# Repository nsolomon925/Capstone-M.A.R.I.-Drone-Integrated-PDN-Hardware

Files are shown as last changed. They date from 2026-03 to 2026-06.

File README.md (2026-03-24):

# M.A.R.I. Drone: Integrated Power Distribution Network (PDN)

## Project Overview
This repository documents the design, simulation, and physical implementation of a high-performance Power Distribution Network (PDN) for the M.A.R.I. Quadcopter. As the **Power Systems Lead**, I engineered a triple-domain power architecture capable of supporting high-current flight demands while maintaining clean, isolated voltage rails for sensitive avionics and sensors.

## Key Technical Specifications
* **Dual Battery Support:** Validated for both **3S (12.6V)** and **4S (16.8V)** LiPo configurations.
* **Peak Current Capacity:** Engineered to handle **71.6A peak** during maximum ascent maneuvers.
* **Triple-Domain Architecture:** * **16.8V High-Power Bus:** Direct battery rail for the 40A ESCs and motors.
    * **5V Logic Rail:** Driven by the **AP63300** Buck regulator for the MCU and LoRa modules.
    * **3.3V Analog Rail:** Dual **TLV75533** LDOs providing isolated power for the IMU and Barometer.
* **Flight Endurance:** Optimized for a **9.4-minute** hover time.
* **Safety Systems:** Integrated hardware-level voltage divider for a **1.4V** battery monitoring threshold.

## Repository Structure
The project is organized into a professional engineering hierarchy for technical validation and production:

### 📁 `/analysis`
Contains all theoretical and simulated validation for the power system.
* **`/mathcad`**: Static power integrity and thermal loading worksheets.
* **`/spice`**: LTspice transient and noise analysis for 12.6V and 16.8V domains.
* **`/power_budget`**: System loading models and endurance calculations.

### 📁 `/design`
Includes the physical and logical implementation of the hardware.
* **`/hardware`**: Hierarchical schematics, PCB layout captures, and 3D renders.
* **`Block Diagram.pdf`**: High-level system architecture and signal flow.

### 📁 `/budget`
Focuses on the production and component selection.
* **`Bill of Materials.xlsx`**: Full parts list with 35V+ rated components for 4S compatibility.

### 📁 `/reports`
Executive summaries and performance verification.
* **`Final_Design_Review.pdf`**: Comprehensive system overview.
* **`Project_Report.pdf`**: Final flight testing and hardware validation results.

## Engineering Highlights
* **Parasitic Modeling:** Used LTspice to simulate the impact of **12 AWG** wiring and **XT90** connector inductance ($L_w$) on voltage ripple using parametric stepping.
* **EMI Isolation:** Implemented dual LDOs to decouple high-frequency switching noise from sensitive flight sensors.
* **Robustness:** All power components are rated for **25V-35V** to ensure safety during the high-voltage swings of a 4S battery.

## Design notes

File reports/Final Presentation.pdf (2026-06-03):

# MARI Drone

Team:
Seth Iris Canonigo
Connor Prior
Christopher Ruiz-Guerra
Nahom Solomon

## Modular Aerial Real-Time Instrument (M.A.R.I)

### Flying Quadcopter Drone

Features:

- User control with Radio Controller
- Self-Stabilization
- Altitude-lock
- Modular - easily able to add additional features

## Quadcopter Drone Flight

- We use 4 motors/propellers to control the drone
- Forward/back/left/right movement is achieved by tilting the drone using unequal levels of thrust in each motor
- Propellers must move in opposite directions so the drone doesn’t spin in the same direction as the propellers
- Control Equations:

Motor(Front Left) = throttle - roll - pitch + yaw

Motor(Front Right) = throttle + roll - pitch - yaw

Motor(Rear Right) = | throttle + roll + pitch + yaw
Motor(Rear Left) = | throttle - roll + pitch - yaw
- Values for throttle, roll, pitch, and yaw will be controlled by user

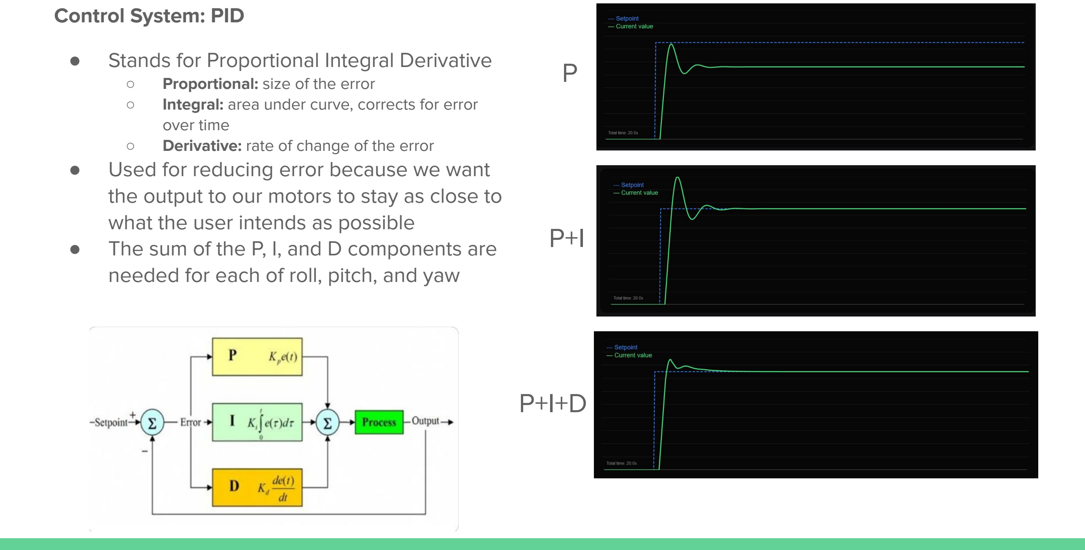
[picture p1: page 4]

Control System: PID

- Stands for Proportional Integral Derivative
- Proportional: size of the error
- Integral: area under curve, corrects for error over time
- Derivative: rate of change of the error
- Used for reducing error because we want the output to our motors to stay as close to what the user intends as possible
- The sum of the P, I, and D components are needed for each of roll, pitch, and yaw

P

P+I

P+I+D

## Block Diagram

## Power

Key Priorities:

- Stable operation across battery voltage drop
- Noise mitigation and safe filtering
- Battery health monitoring safety

## Power Overview

Power Architecture:

- High Current Path: Battery -> ESCs (up to 104 A / 16.8V and 110.4 A / 12.6 V)
- Low Current Path: Battery -> Buck Converter -> LDOs
- Separate regulated rails for MCU, RF Receiver, Sensors, LORA
- Integrated ADC-based battery monitoring circuit for live voltage tracking
Major Loads:
- ESCs: 104 A Peak / 16.8 V (26 amps per ESC) or 110.4 A Peak / 12.6 V (27.5 amps per ESC)
- 5 V Rail: ~0.84 A (RF Receiver + LDO input)
- 3.3 V Rail A: ~0.203 A (IMU, Lora)
- 3.3 V Rail B: ~0.409 A (MCU, Barometer, Oscillator)

## Battery: Gens Ace 3SP1 LiPo

- 11.1 V nominal, 12.6 V max
- 5300 mAh, 60C discharge
- 318 A max continuous output capability
- Easily supports drone peak ~110 A flight load

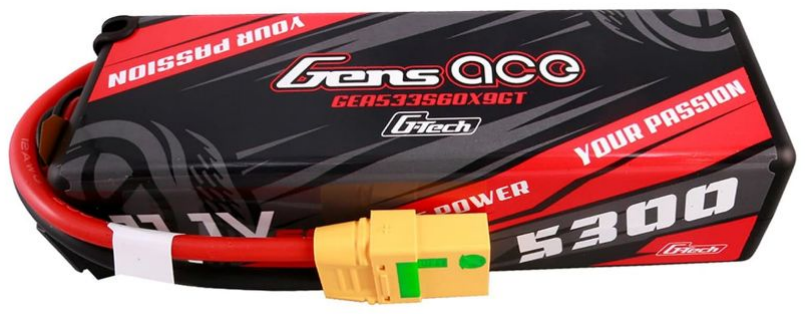
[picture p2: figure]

- XT90s main connector; supports high current draw
- Powers entire system
- Battery stress < 33% of rating
- Expected Flight Time (413g / 0.911 lbs):
- Hover: 3.846 - 4.613 min
- Ascend: 2.88 - 3.455 min

## 5 V Buck Converter - AP63300WU-7 (Diodes Inc.)

- 3A synchronous buck regulator
- Converts 16.8 V (max battery) ---> 5 V regulated
- High efficiency (~90%) to reduce heat and extend flight time
- Powers RF receiver and supplies input to two separate 3.3 V LDO rails
- LC output filter + bulk capacitance to minimize ripple from ESC switching

## 3.3 V LDO Regulator: TLV75533PDYDR (Texas Instruments)

- Low noise, precision LDO rated for 500 mA
max
- Regulates 5 V → 3.3 V for MCU & sensors
- LDO A supports ~204 mA combined load (IMU, LORA)
- LDO B supports ~409 mA combined load (MCU, Barometer, Oscillator)
- Provides clean supply ideal for sensitive components

## Schematic: Power

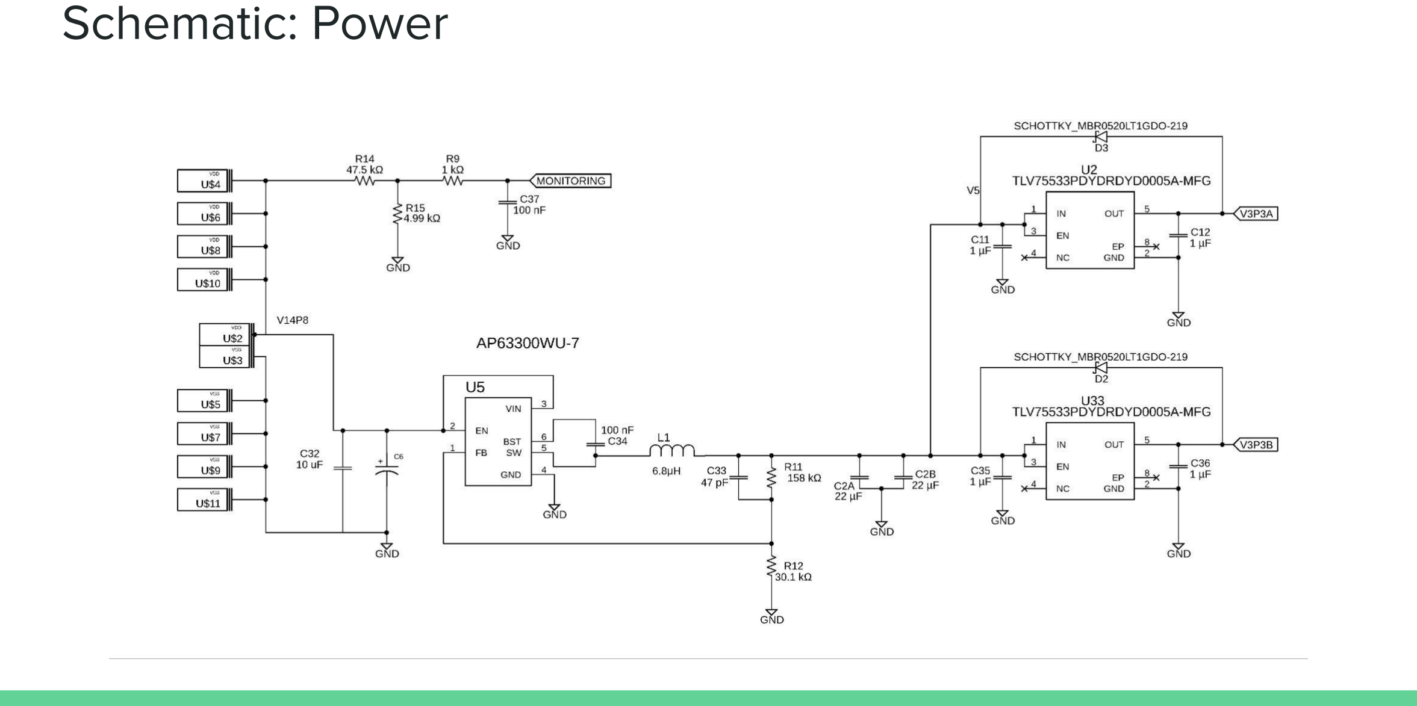
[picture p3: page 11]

## Schematic / LT Spice (12.6 V / 16.8 V)

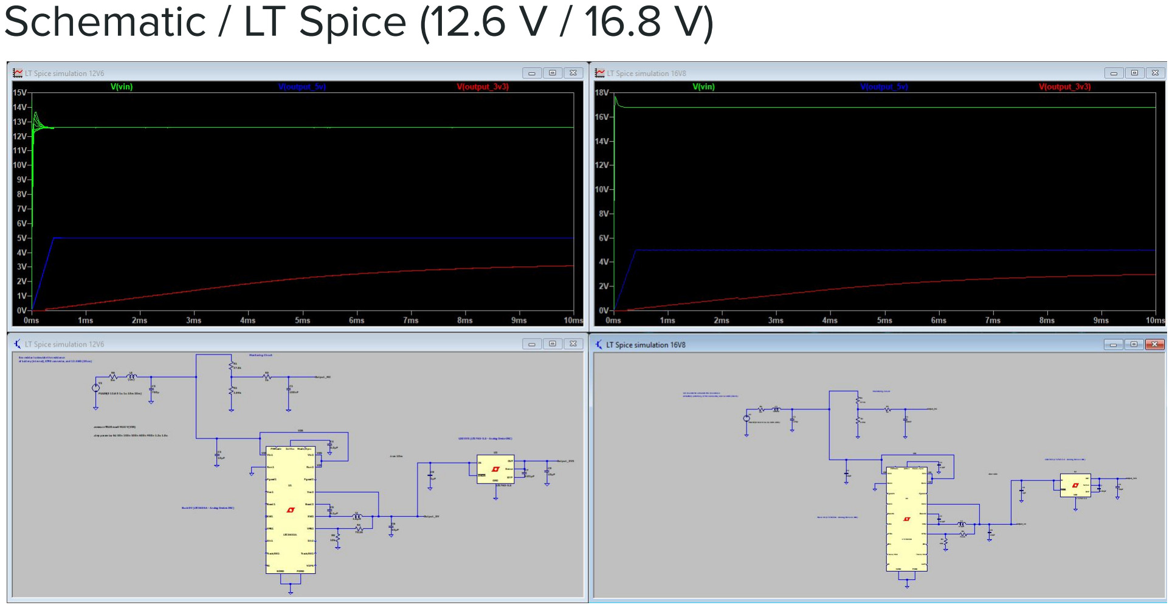
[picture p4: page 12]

## PCB Layout: Power

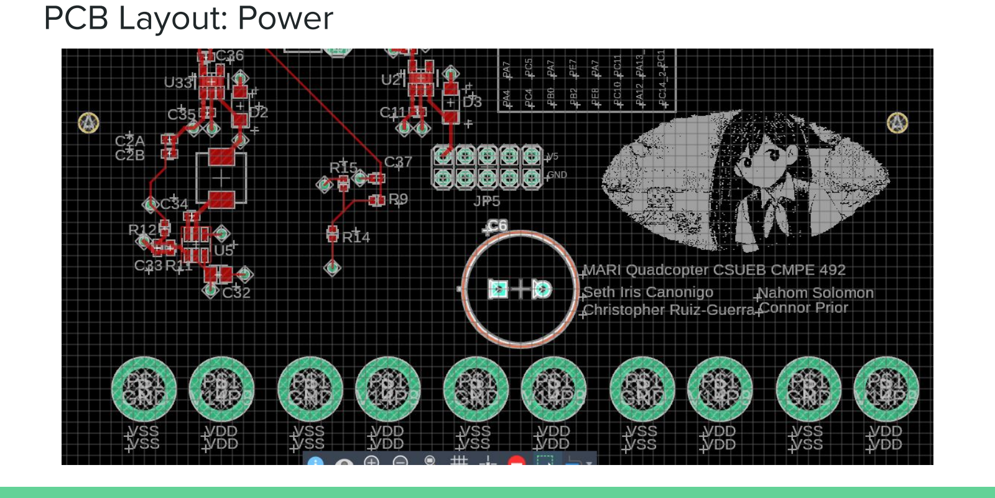
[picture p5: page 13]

## PCB Layout: Power

## Radio Controller / Receiver

Purpose

- Controller: Allows user to control the drone using control sticks.

Communicates with Radio Receiver in Express Long Range System

(ELRS) protocol

- Receiver: Allows the use of 6 PWM Channels, Requiring only 4 Channels

to control Pitch, Yaw, Roll and Throttle

Output

- Controller ⇒ Receiver ⇒ MCU⇒ ESC⇒ Motor
- PWM signals are taken as input for our MCU to calculate balanced PWM outputs to our ESC

## Electronic Speed Controller(ESCs) : RCElectricParts 30A

- Main Purpose: Control rotational speed of motors
- Utilizes PWM signals to vary power from battery towards

motors through MOSFET switching

## Motors: Emax ECO II Series 2807 3-6S 1300KV

- Purpose: Spins propellers to generate
thrust per motor
- Expected weight 5lbs
- Each motor must produce 567 Grams of thrust
- Allows maneuverability via flight equations

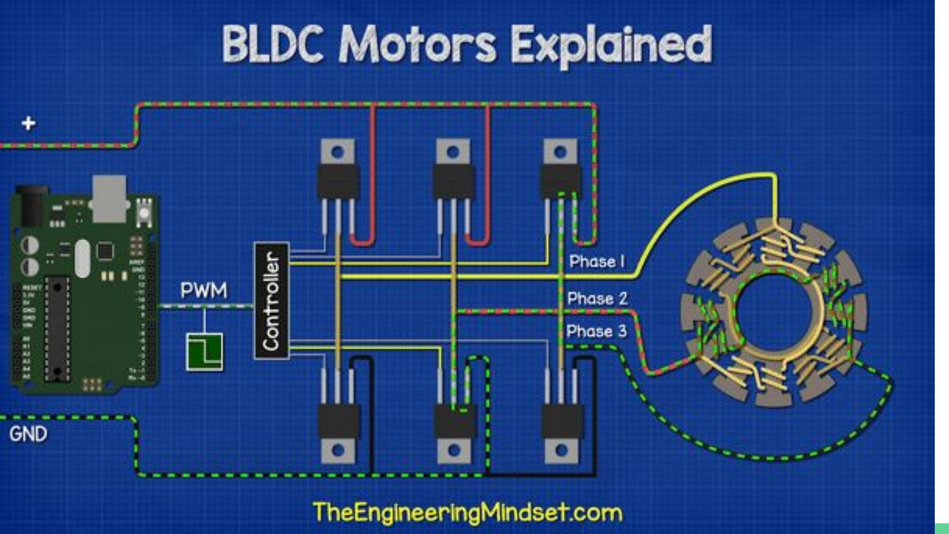
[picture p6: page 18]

## IMU (Inertial Measurement Unit): BNO085

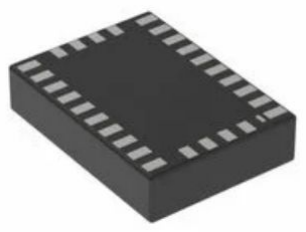
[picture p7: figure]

- Main Purpose: Stabilizing the Drone
- Detects the orientation and
speed/acceleration of the drone
- Main Components:
- Gyroscope - measures angular velocity
- Accelerometer - measures linear acceleration
- Magnetometer - measures direction of magnetic field
- Fusion mode allows the BNO085 to:
- Calculate Euler Angles (Roll, Pitch, Yaw)
- Minimize error using multiple sensors
- Sends data to the microcontroller through I2C protocol

## Schematic: BNO085

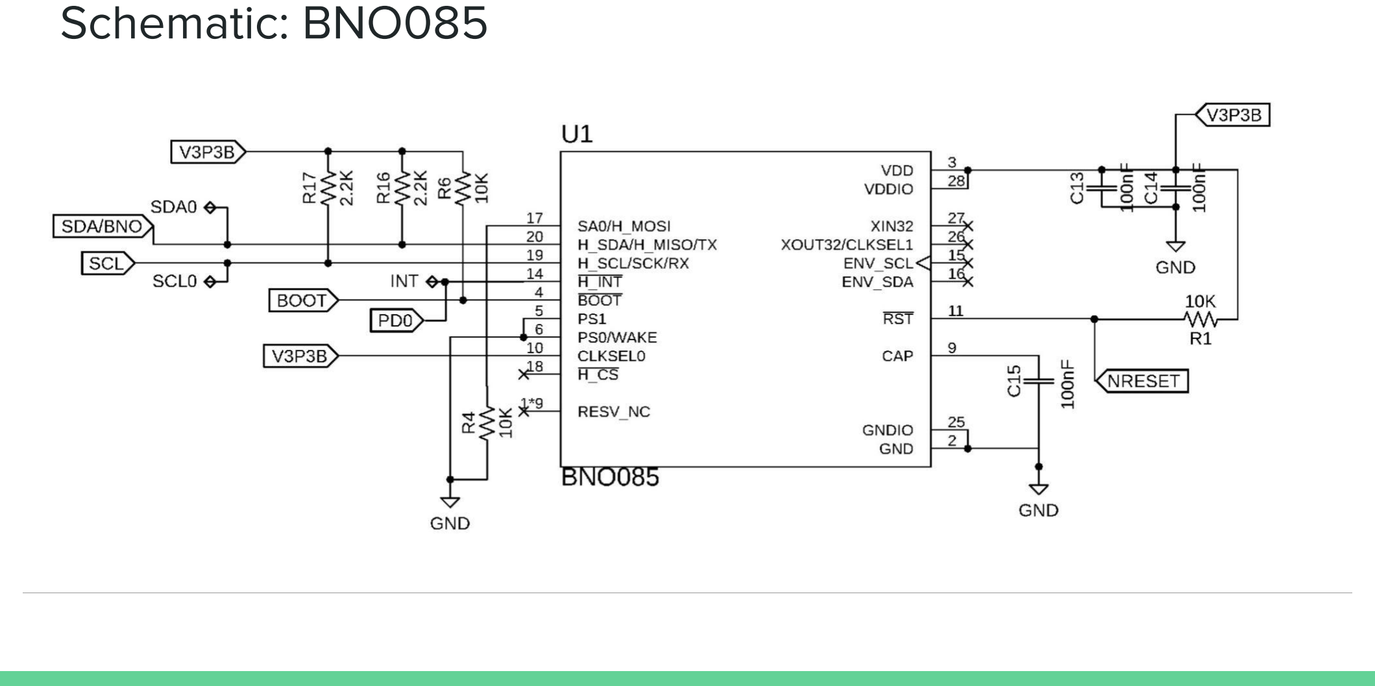
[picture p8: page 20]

## PCB Layout: BNO085

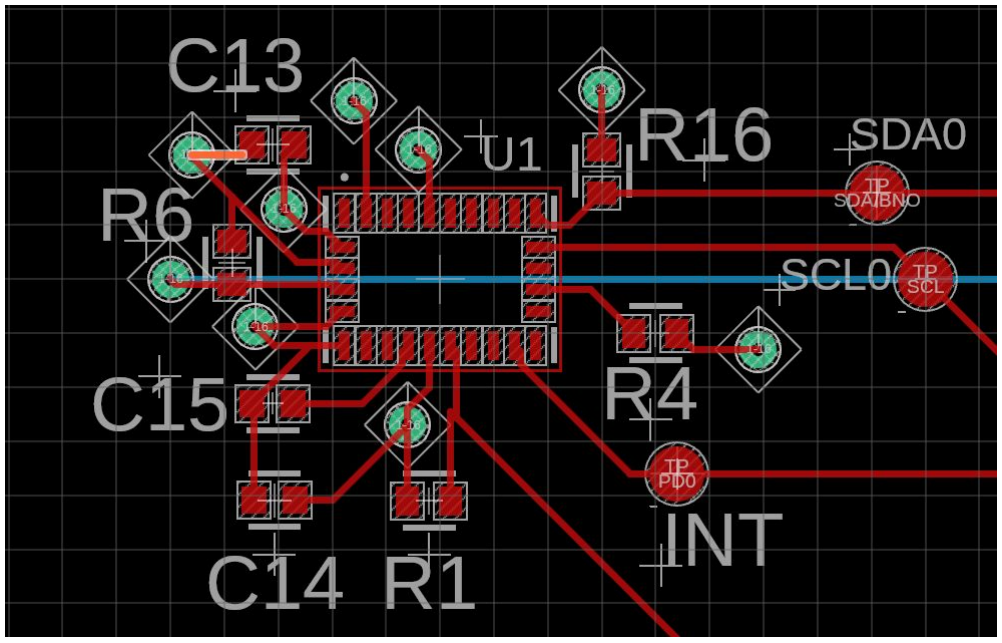
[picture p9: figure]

## Barometer: BMP581

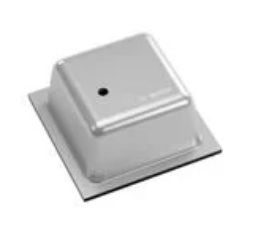
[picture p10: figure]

- Main purpose: measuring the altitude of the drone.
- Sends data to microcontroller through I2C.
- Data will be used to limit the height the drone will be able to fly at.

## Schematic: BMP581

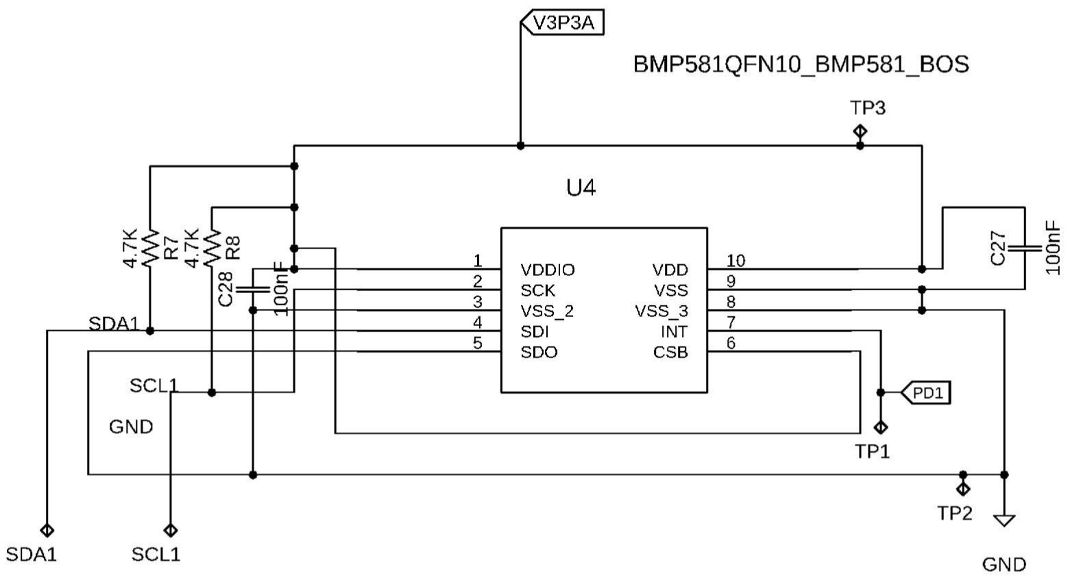
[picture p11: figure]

## PCB Layout: BMP581

## Microcontroller STM32F756VGT6

- MCU is the brain of MARI.
- Takes in input signals, runs all calculations, and outputs the PWM signals for the ESCs.
- Runs at 216 MHz with external crystal
- 100 total pins

Voltage warning light (1 in signal)

Barometer I2C (3 in signals)

IMU I2C (3 in signals)

16 MHz Oscillator (1 in signal)

RF PWM (4 in signals)

ESC PWM (4 out signals)

13 input pins

5 out pins LoRa UART RX

LoRa UART TX

## Schematic: Microcontroller 1

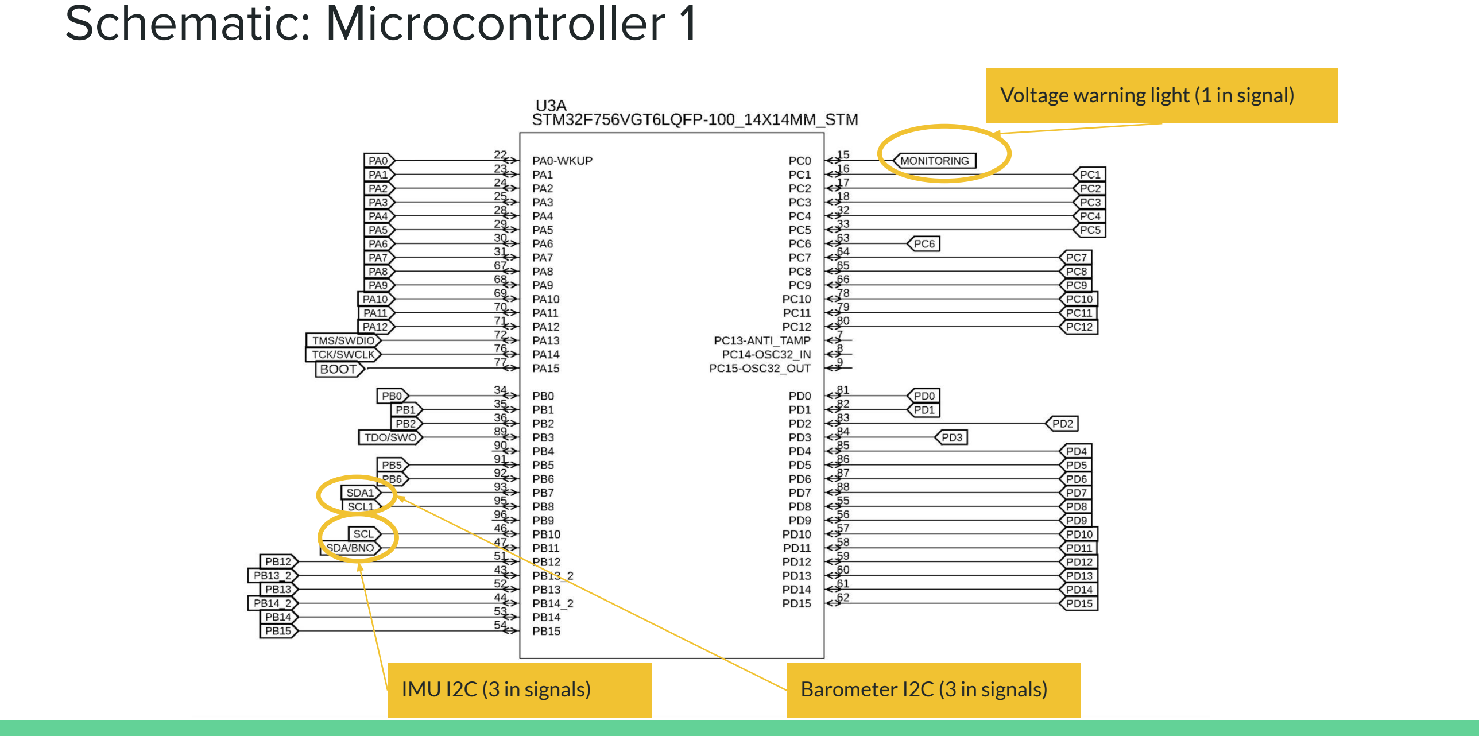
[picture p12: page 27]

Voltage warning light (1 in signal)

IMU I2C (3 in signals) | Barometer I2C (3 in signals)

RF PWM (4 in signals)
ESC PWM (4 out signals)

## Schematic: Microcontroller 2

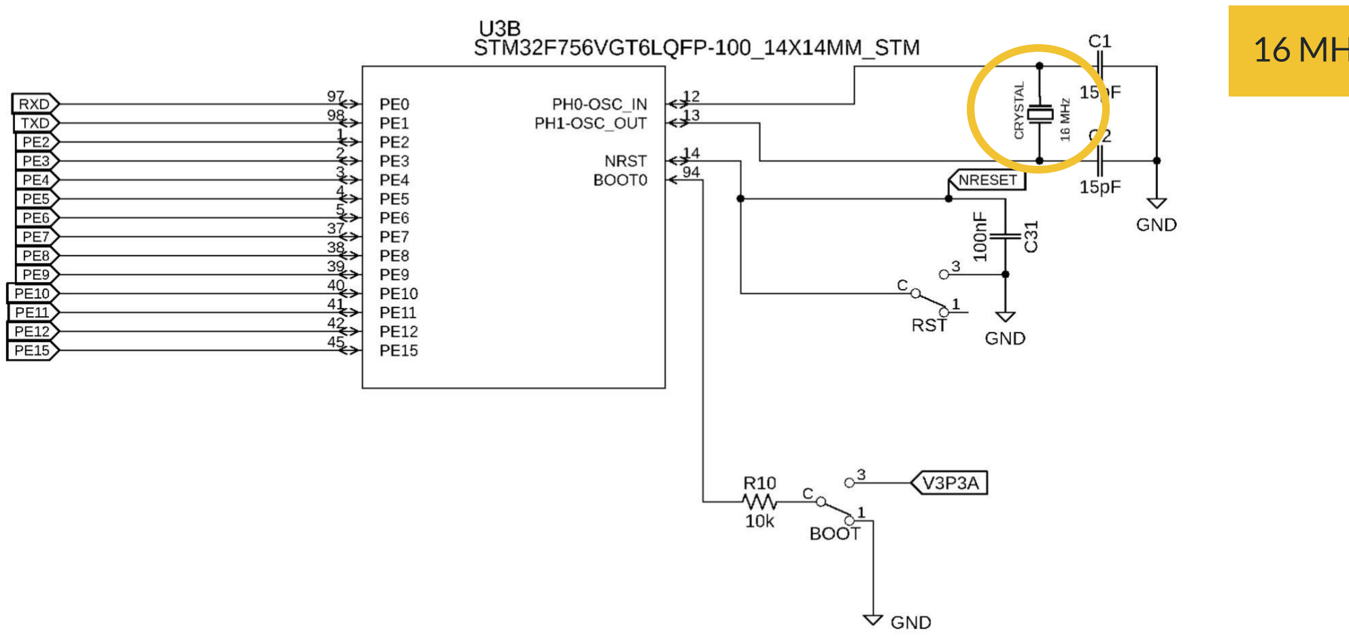
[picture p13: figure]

16 MHz Oscillator (1 in signal)

## Schematic: Microcontroller 3

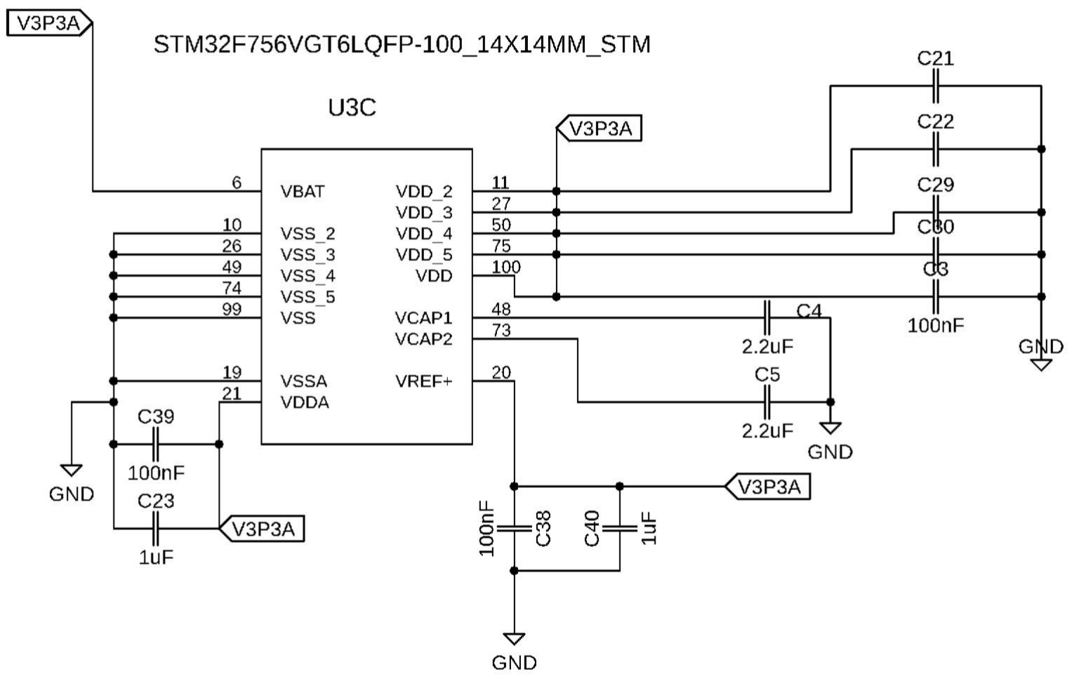
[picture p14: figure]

## PCB Layout: Microcontroller

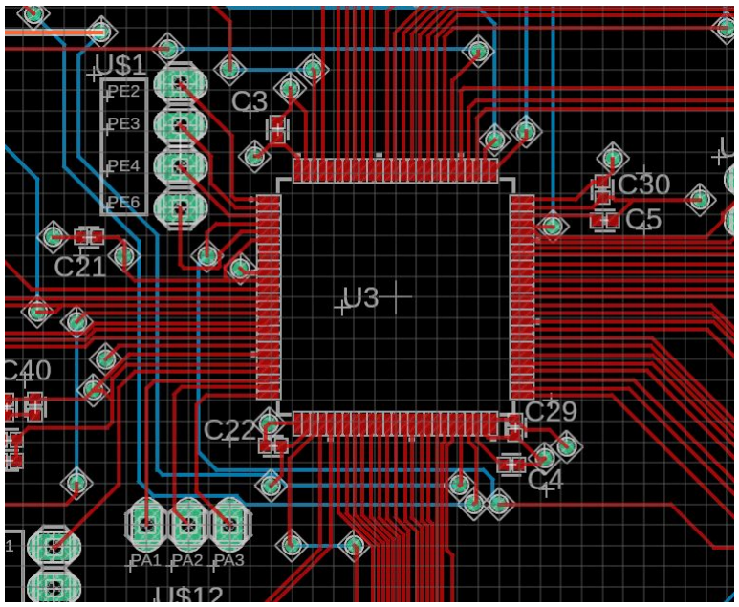
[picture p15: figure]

## Long Range (LoRa) Telemetry: REYAX RYLR998

RYLR998 module is a UART-controlled
LoRa transceiver.

It is low power (56.6 mA) and cheap

Can send data with AT+SEND=...

Can receive data with +RCV=...

Depending on configuration, it can go over a kilometer in distance with limited data rates.

## Hassles of LoRa

- Data rate is abysmal for real-time telemetry
- Only 240 Bytes per payload
- Default Throughput: 190 Bytes/s
- Default Latency 190.7 ms

If I send a packet per second, there will be data loss.

Obviously this is not including RX.

Meaning we had to be picky about what we send from the drone to the receiver

## SWD (Serial Wire Debug) via ST-Link (SWJ)

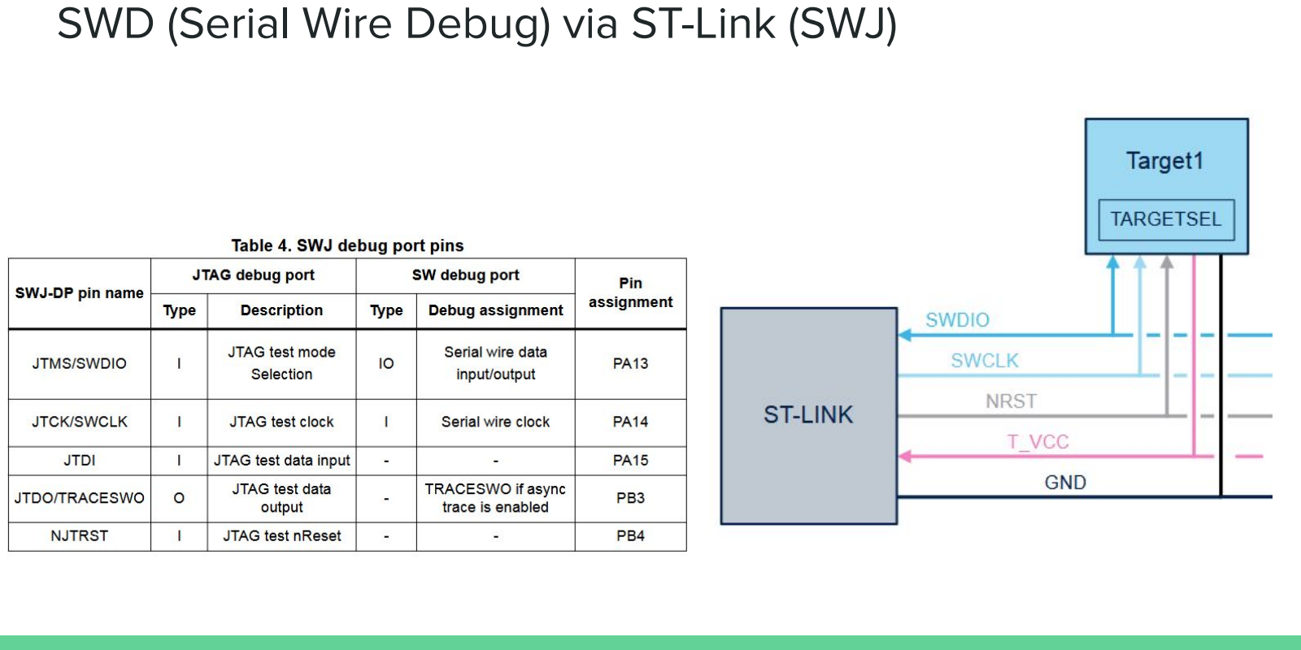
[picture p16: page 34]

## Schematic and PCB Layout: Serial Wire Debug Programming Pins

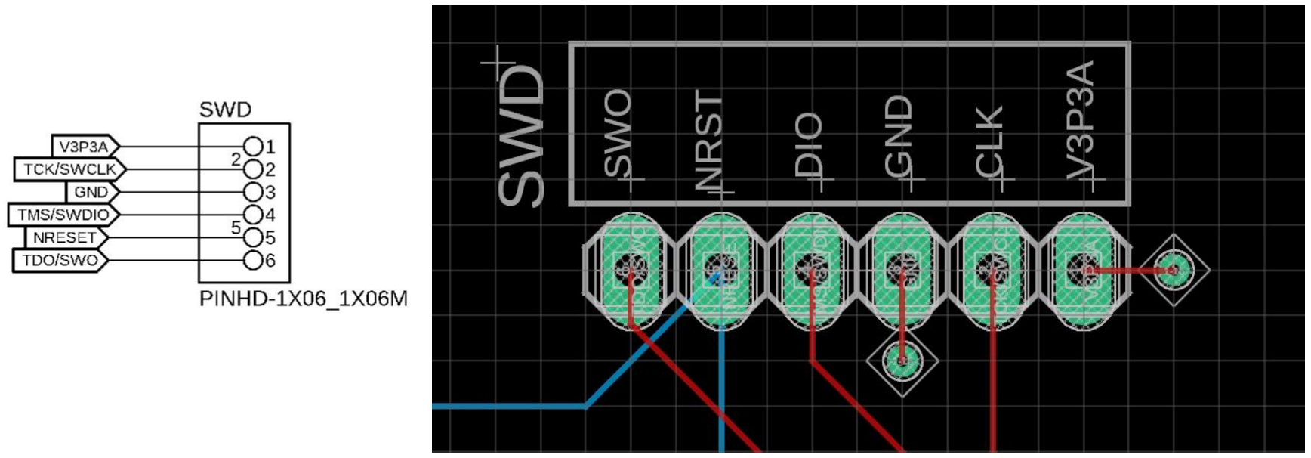
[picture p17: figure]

## Extra Pins

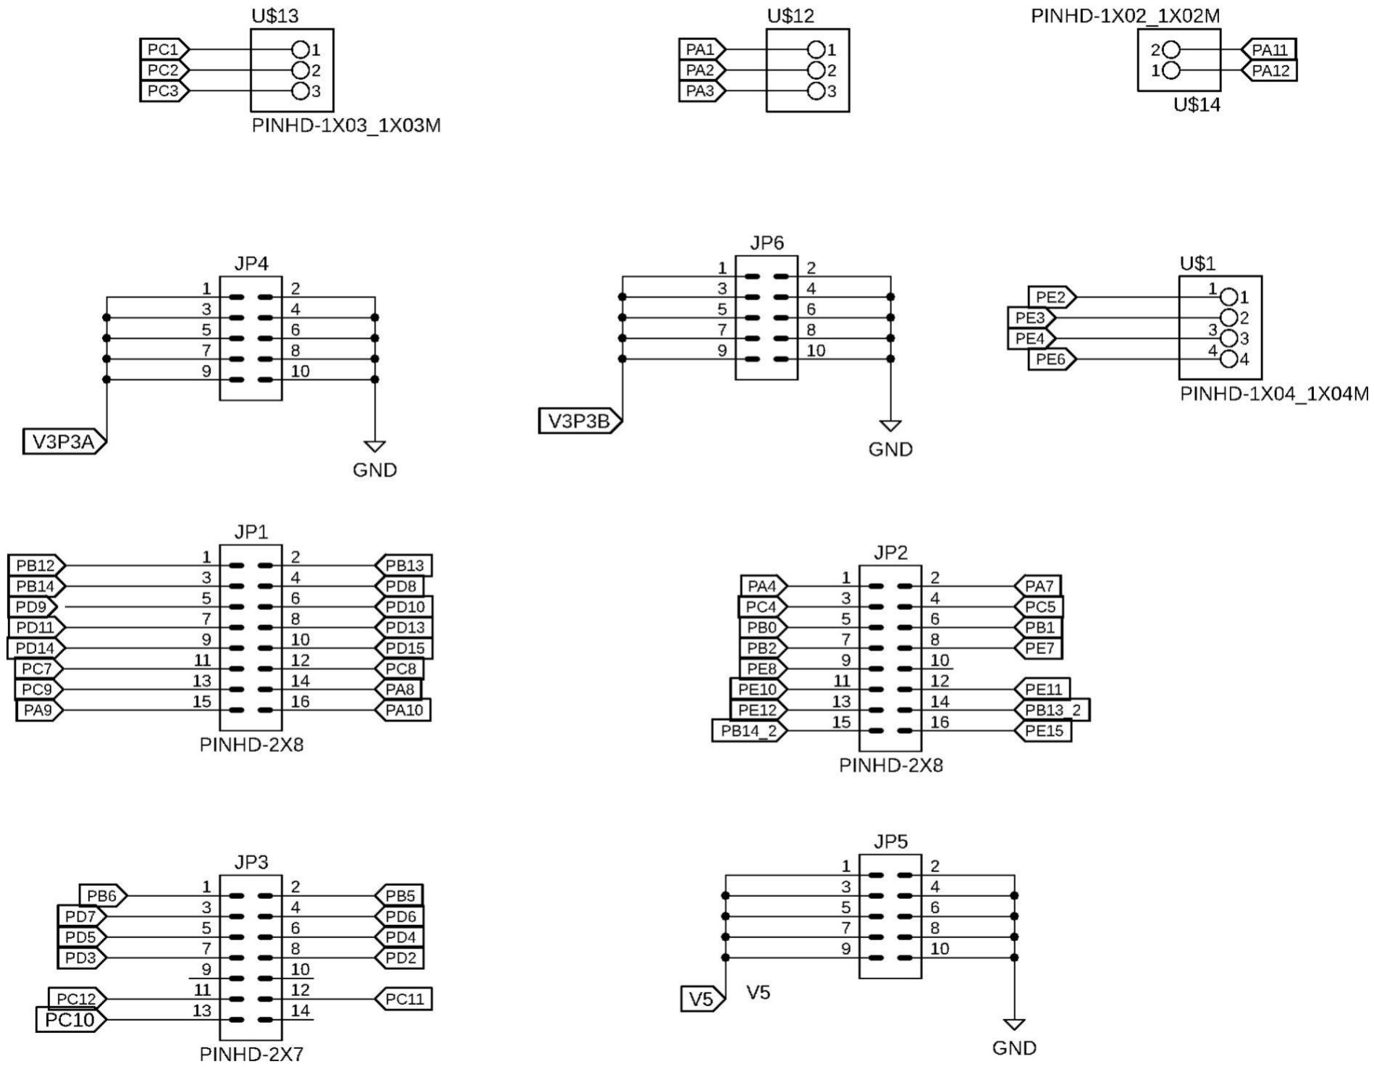
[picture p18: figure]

## Overall Schematic

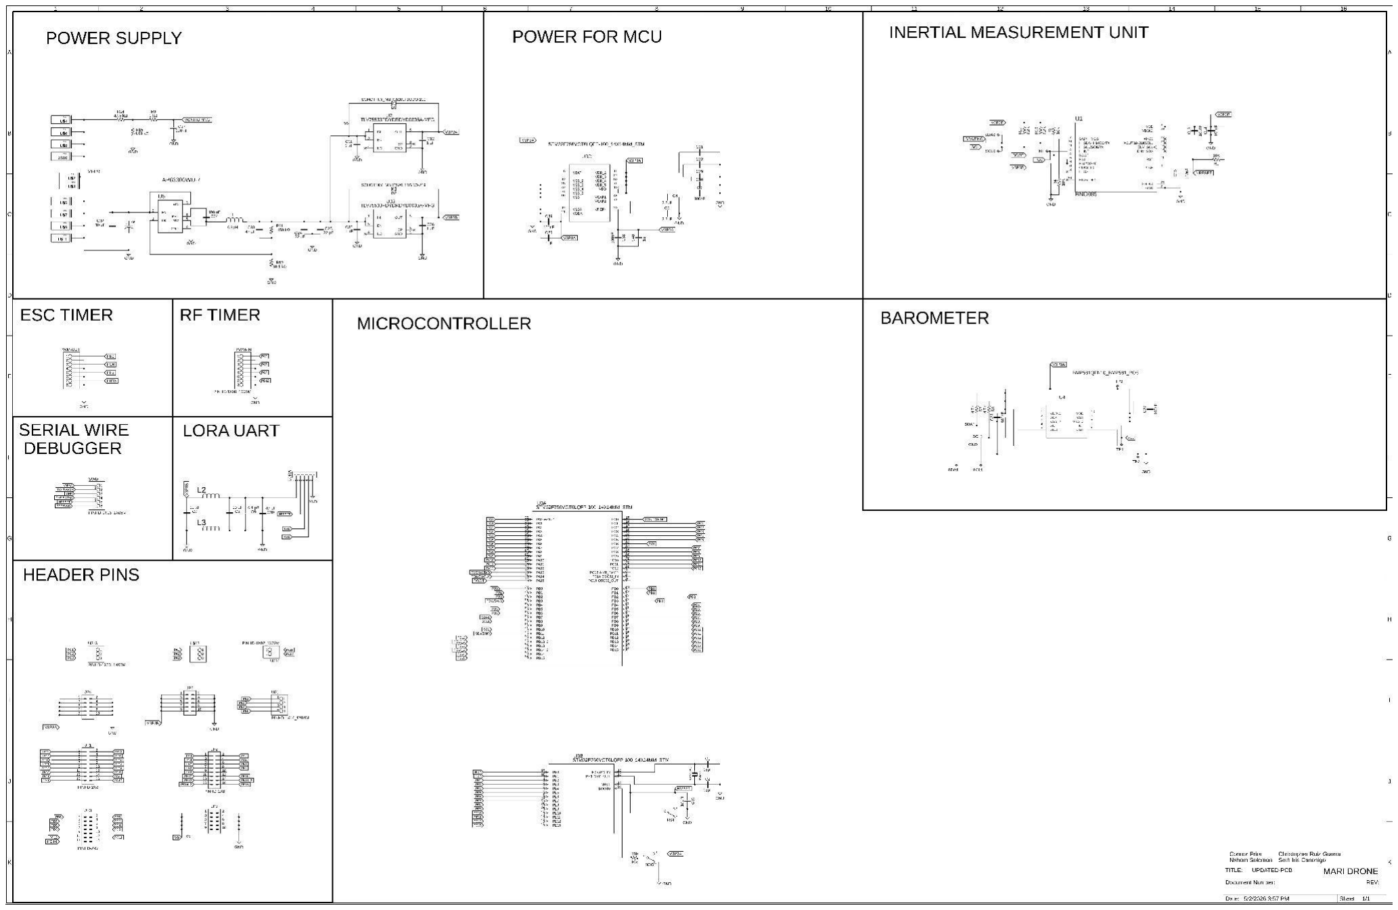
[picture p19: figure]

## Software STM32CubeIDE

- It is the development IDE tool we are using for
programming the
STM32F7.
- It does the entire bootup sequence for us and also
generates initialization
code for all of the
peripherals
- All of this is loaded into the STM’s flash memory

## Official API and drivers

## DMA and NVIC (and EXTI)

Because UART is very slow (blocking), it essentially slows down our flight loop, even if the CPU is running at 216 MHz.

That’s why we used Direct Memory Access (DMA) to combat that.

It moves UART8 TX data from Memory to Peripheral and RX data from Peripheral to Memory without slowing down the flight.

The Nested Vectored Interrupt Controller (NVIC) basically handles all our interrupts even the external ones (EXTI)

## Real-time Operating System (FreeRTOS)

Instead of one giant loop, we used a
Real-Time Operating System (RTOS) to
help manage the various tasks.

FreeRTOS is a popular RTOS and is actually Middleware in CubeIDE using the “wrapper" called CMSIS-RTOS2 to link with the FreeRTOS kernel.

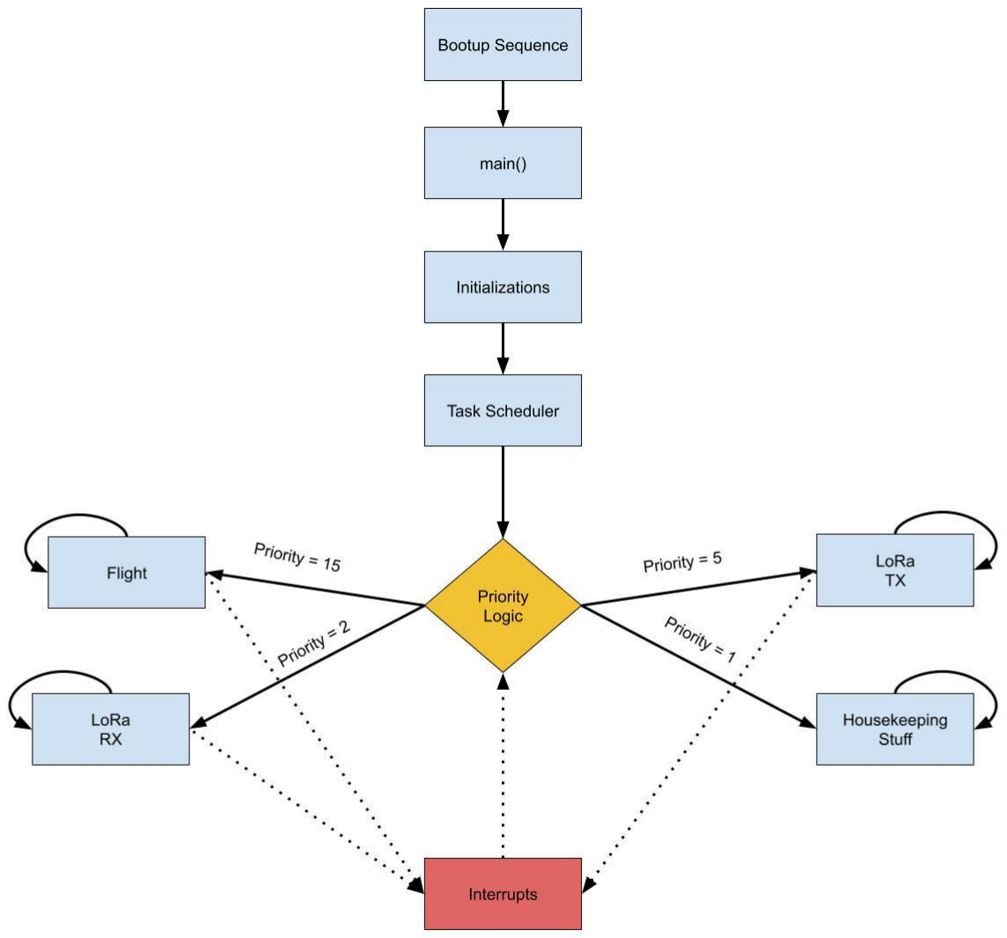
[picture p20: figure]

There are four tasks (FlightTask, TelemTx, TelemRx, and Housekeeping) for the RTOS and three interrupt conditions.

Realistically, running four at the same time with a single core is impossible.

BUT… we can give the illusion that it can by switching between tasks really fast and efficiently via a task scheduler.

## Tasks

## FlightTask (800 Hz - Interrupt-driven)

Purpose: Handles the core flight control
loop, including reading IMU data,does
PI, and updating motor PWMs.

## TelemRx (Interrupt-driven)

Purpose: Processes RX UART data from the LoRa, including handling "Sunny" pings, "Mari" commands.

Purpose: Manages the scheduled transmission of telemetry data (IMU, motor states, battery, and PID values) back to the ground station.

## TelemTx (100 Hz)

## Housekeeping (10 Hz)

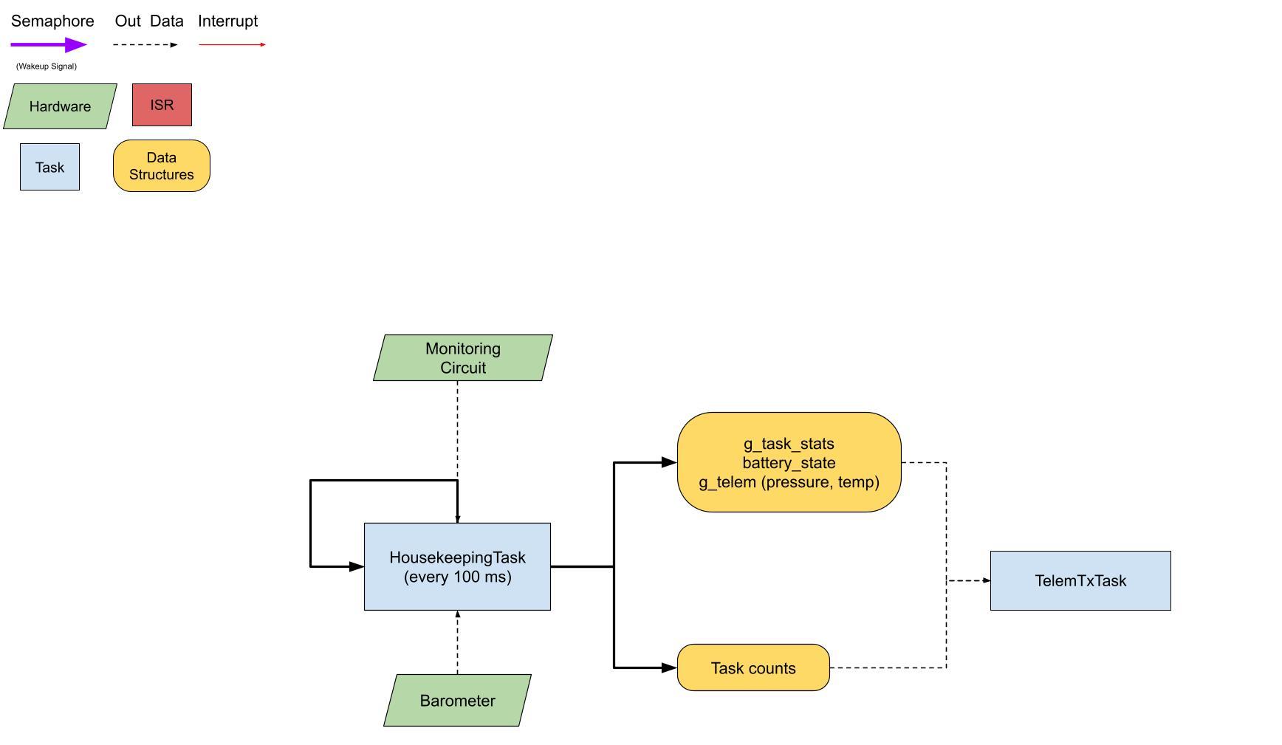
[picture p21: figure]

Purpose: It calculates how loops per second each task does (Hz), updates CPU usage statistics, reading battery voltage, and updating the barometer data.

## Task Priority

To achieve this, task execution is based on priority and must also ensure that resources are allocated properly.

It uses a combination of polling and interrupts to achieve our results
TelemRxTask

FlightTask

HousekeepingTask

High

Medium

Low

TelemTxTask

## Tasks for the MARI

## Task Scheduler

RTOS; LOW; MEDIUM; HIGH; ISR; tick; Housekeeping; Flight; Sensor; PID

## MARI LoRa Monitor

To keep track of the data and parse the data we get from the LoRa telemetry.

It functions as serial monitor, graphing tool,

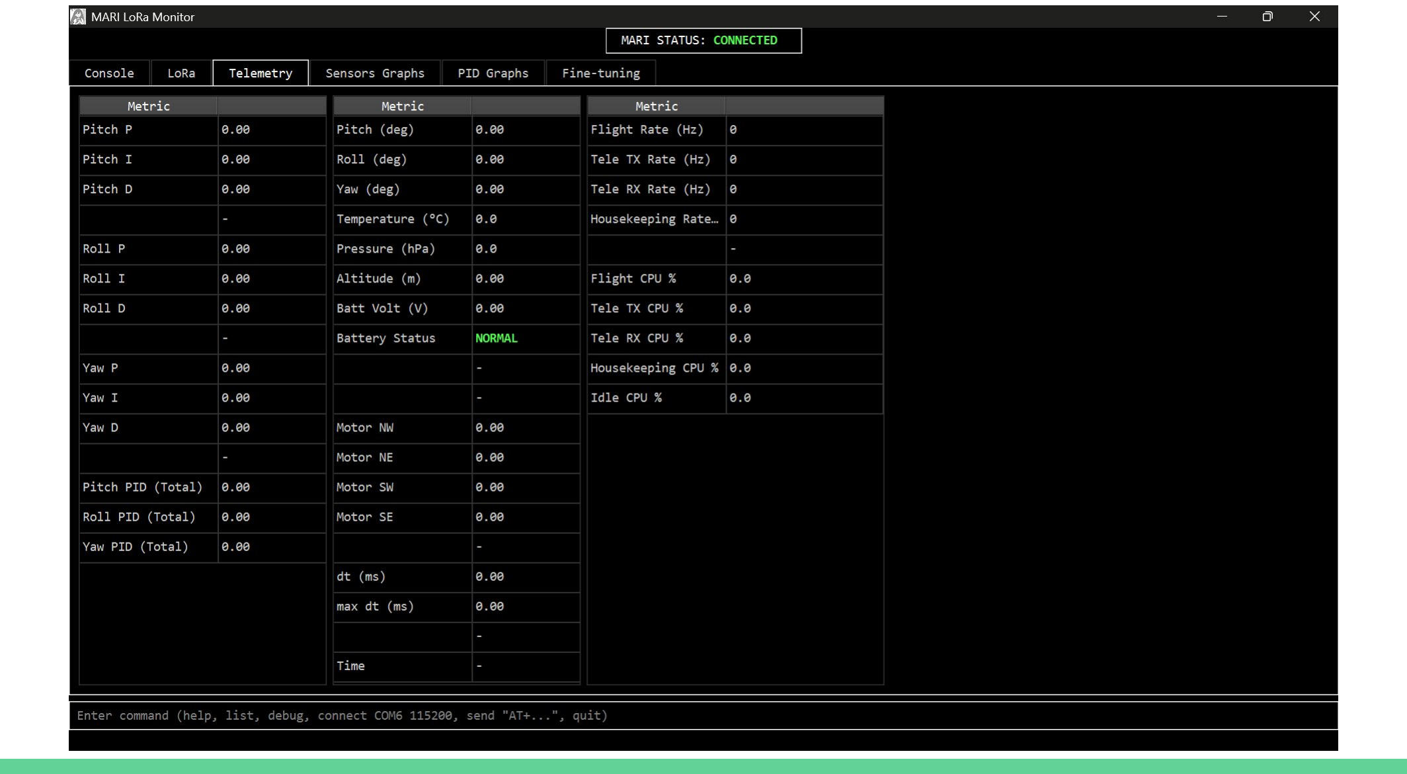
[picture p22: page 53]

## Version 1 and 2 (Plain terminal)

## Version 3 (switched to Textual)

## Version 4 (Remote Monitor)

## Version 5 (switched to GUI, specifically PyQT6)

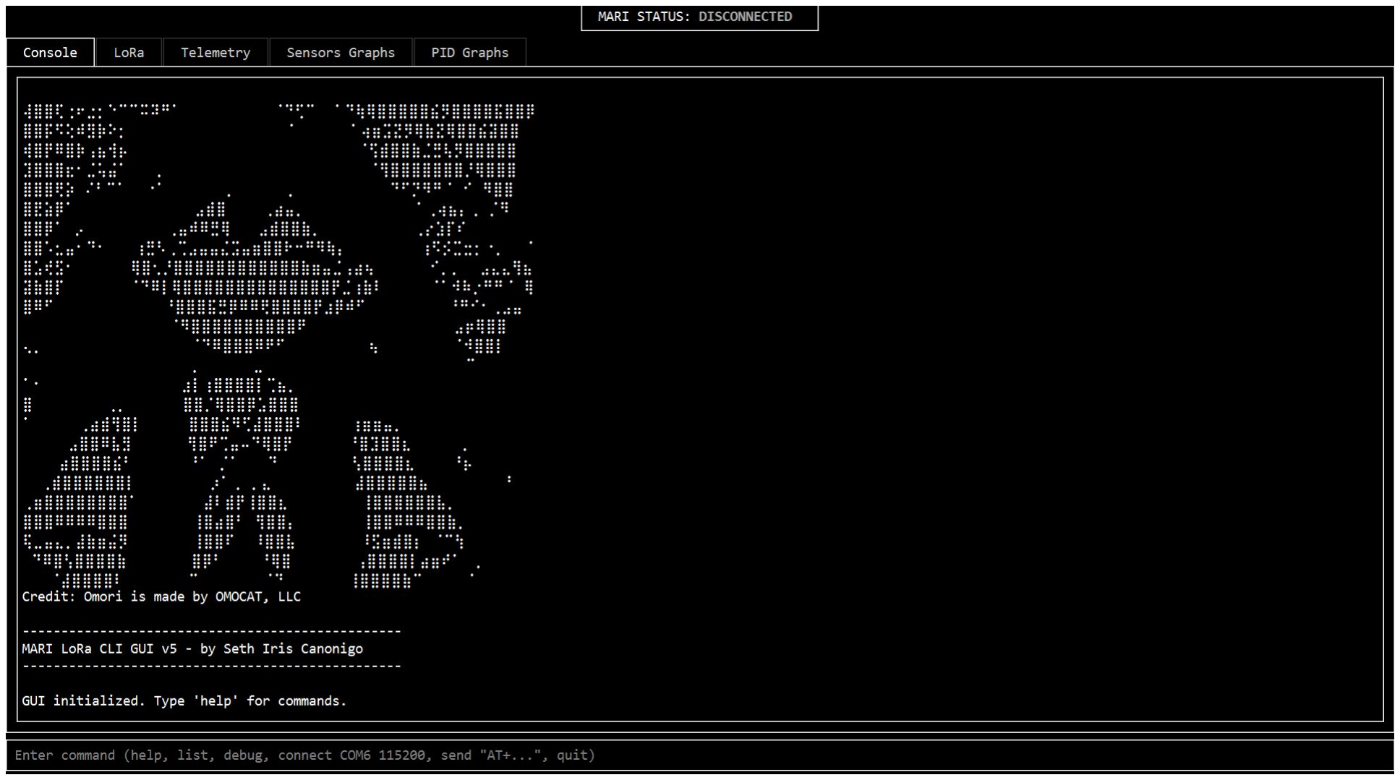
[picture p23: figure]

## Graphs

## Difficulties: Needed to respin PCB

The first iteration of our PCB design was riddled with flaws:

- Zener diode was backwards
- Ultra-short burst, high-current draw causing a voltage spike
- The IMU was stuck in HID outputs
- LoRa was drawing too much current for the LDO
- LoRa had a lot of noise due to incorrect application configuration
- Missing VDD and VSS labels

## PCB Failure Analysis: Fried BUCK & IMU

## Causes: Transient Voltages

## New PCB

Changes

- Faster IMU (400 Hz vs 100 Hz)
- More power for LoRa (22 dBm vs 1 dBm)
- We have two LDOs for two separate 3.3 V planes
- New buck converter with inductor
- Big 1000 uF cap to dampen the spike
- Labeled everything

## Old PCB

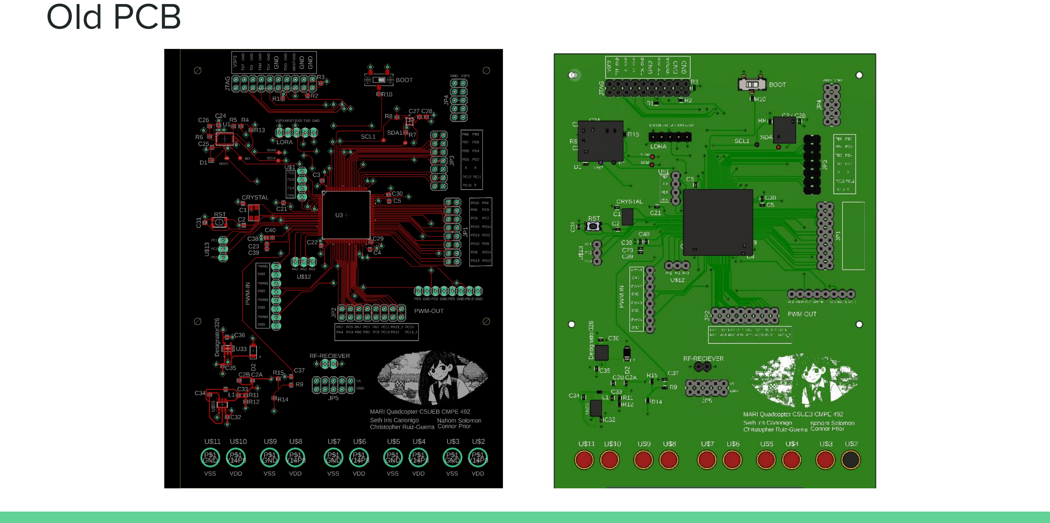
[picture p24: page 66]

## New PCB

## Future Improvements

- Smaller PCB
- Better components with a higher sampling rate
- Included protocol with larger bandwidths and faster rates
- Better structured control system
- Additional domain for expansion ports
- Monitoring Circuit LEDs visible from distance
- Power switch
- Using SWV more often and knowing its features, like plotting

## Conclusion

Quadcopter RC Drone with
self-stabilization and altitude-lock

Operating System included to run our tasks almost concurrently.

The main goal of our drone is just to get it to fly stable in the air.

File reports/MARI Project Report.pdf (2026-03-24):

Connor Prior | Email: cprior3@horizon.csueastbay.edu (Team Leader)
Nahom Solomon | Email: nsolomon@horizon.csueastbay.edu
Christopher Ruiz-Guerra Email: cruizguerra@horizon.csueastbay.edu
Seth Iris Canonigo | Email: scanonigo@horizon.csueastbay.edu

## Modular Aerial Realtime Instrument (M.A.R.I)


### Introduction:

Our Senior Design Project is a quadcopter drone that is controlled by a radio controller

that will be able to fly and perform basic aerial movements. A radio controller will send four

radio signals to our receiver on our drone, which will send PWM signals to our microcontroller.

These signals will control the throttle (upward/downward movement), yaw (rotation), pitch

(forward/backward movement), and roll (side to side movement). The microcontroller will alter

these signals to keep the drone level with the help of an IMU(Inertial Measurement Unit) and a

barometer, which will detect the orientation of the drone so it can correct its movement to stay

level in the air, and also stop its vertical movement when it reaches a certain height. Once the

microcontroller computes the correct PWM signal to send to each motor, those signals will be

sent to four Electronic Speed Controllers (ESCs), which will turn those PWM signals into

3-phase power to the four motors. These motors will turn the propellers that lift our drone into

the air and control the drone’s movements.

### Basic Movement:

The quadcopter flies using 4 propellers with motors and movement is generally

controlled by increasing/decreasing the thrust generated by these propellers to change the

throttle, pitch, roll and yaw of the drone. These propellers must move in different directions to be

able to tilt and rotate it without it spinning out of control while keeping the net torque on the

drone at zero. The throttle is increased by providing thrust from all four propellers equally, while

pitch, roll, and yaw are varied as shown in the figure below.


Figure from Hanewitch, Tim

## Subsystem Descriptions:

### Microcontroller Unit:

The Microcontroller Unit (MCU) is the “brain” of MARI as it handles the data processing

and communication between the other subsystems. It continuously gathers data from sensors

such as the gyroscope, the accelerometer, and the barometer, then runs real-time control loop

algorithms that calculate how the motors should respond given the data from the sensors. Using

the timers, the MCU generates PWM to control the electronic speed controllers (ESCs).

The advanced timer, TIM1, will generate the PWM for the ESCs which will go directly

through the respective GPIO pins via the Alternate Function Multiplexer, specifically AF1.

Data from the IMU and barometer will be directly stored to the RAM via the Direct

Memory Controller, specifically DMA1, through the APB1 bus. This is done to save the main

CPU from constantly handling interrupts for every therefore massively reducing overhead time.

They will be connected to two separate I2C buses and ground. For the ELRS RF Receiver, we

will be using four 32-bit timers, two channels each.

All pins are connected through their specific ports and AF as per stated in the datasheet.


Component Specs:

Supply Voltage: 3.3 V

Total Max Supply Current: 320 mA

Max Supply Current per VDD line: 100 mA

SRAM: 1 MByte

Flash Memory: 320 KBytes

### Power:

The drone’s power system is supplied by a CNHL 6200 mAh 14.8 V (4S) 30C LiPo

battery with an XT90 plug. The battery’s 30C C-rating corresponds to a continuous discharge

capability of 186 A, with its 60C burst rating allowing up to 372 A for brief periods, as defined

by the battery’s capacity and design. The XT90 connects to a bullet plug adapter, which

provides the connection to the PCB. From the PCB, power is routed along two paths. The first

path delivers battery voltage to the Electronic Speed Controllers (ESCs) via XT60 with bullet

plugs, which convert the DC input into three-phase AC (3P-AC) to drive the motors. The second

path uses two regulators to step the battery voltage down for the electronics: a buck converter

generates a 5 V rail for the RF receiver with high efficiency, avoiding the ~70% power loss that a

linear regulator would waste as heat, and a low-dropout regulator (LDO) provides a stable 3.3 V

rail with reduced noise for the microcontroller, barometer, internal measurement unit (IMU), and

oscillator.

A voltage-monitoring circuit is integrated into the PCB, dividing the battery voltage and

feeding it into the MCU’s analog-to-digital converter (ADC). The MCU interprets this divided

voltage and classifies battery health into three alert levels:

- Good (Green): 1.59–1.33 V
- Warning (Yellow): 1.33–1.25 V
- Critical (Red): < 1.25 V

When the battery enters the Warning or Critical ranges (corresponding to low LiPo cell voltage),

the MCU activates an LED alert to notify the user before unsafe discharge thresholds are

reached. This setup balances efficiency with low noise, ensuring reliable power delivery across all subsystems and supporting an estimated flight time of approximately 10 - 20 minutes

depending on flight conditions.

Component Specs:

Voltage range: 14.8 V nominal (16.8 V max, 13.2 V min under load)

Discharge Rate: 30C Continuous, 60C Burst

Continuous current: 186 A

Burst current: 372 A for ≤ 15 s

Battery Cell Range: 4S LiPo

### Sensors:

IMU(Inertial Measurement Unit) - BNO055

The purpose of the BNO055 inertial measurement unit is to determine the angular

position of the drone, track the acceleration of the drone, and determine the relative position in

respect to a magnetic field (mainly Earth’s). These values will be stored on the BNO055’s

register and then sent to our STM32F microcontroller at 100 kHz in I

2C to regulate the signals

being sent to the motors.

The gyroscope on the chip will determine the angular orientation and acceleration of the

drone. The orientation of the drone will be determined and the pitch, roll, and yaw data will be

stored/sent in the form of Euler angles. The gyroscope will also be able to send angular rate data

to determine the direction and speed the drone is rotating. These measurements are the most

important for stabilizing the drone.

The accelerometer will track the drone’s movement across 3 axes to determine how fast

the drone is going in whatever direction it is moving. It will send this data to the microcontroller,

which will regulate the speed of the motors.

The IMU also has a built-in Kalman Filter in the form of Fusion Mode. This will make all

the measurements done by the IMU more accurate by using the data from multiple sensors to

adjust the data from each individual sensor. This will reduce the error from each individual

sensor.

Component Specs:

Voltage Supplied: 3.3V

Current Supplied: 12.3mA

Barometer - BMP390

The purpose of the barometer is to track altitude data using barometric pressure sensors

so we can control how high the drone can fly. It will store pressure values in Pascals in registers

on the chip and send that data to the microcontroller so we can calculate the height of the drone

relative to the ground. If the measurement from the barometer exceeds a certain value, the drone

will stop accelerating upward.

Component Specs:

Voltage Supplied: 3.3V

Current Supplied: 3.2uA

### Actuators:

ELRS RF Receiver

The M.A.R.I drone will receive PWM signals from the Radiomaster ER6 Express Long

Range system (ELRS) receiver (RX) that connects to our microcontroller. The ER6 has six

different output channels, but we use four of them, which our microcontroller processes with

constraints to output speeds to different motors for throttle, pitch, yaw, and roll. The ELRS

Protocol encodes our gimbal positions into packets that are received from our RX. Due to the

amount of noise our drone experiences the farther it is, A Chirp Spread Spectrum (CSS) sweeps

between 2-2.4 GHz for our receiver to demodulate and reconstruct the signals via dechirping

which gets processed to be a PWM signal at a packet rate of 50 Hz. Our receiver will operate at

5V at 60mA.

Component Specs:

Voltage Supplied: 5V

Current Supplied: 60mA

Electronic Speed Controller (ESC)

The ESC converts our DC power supply into AC by utilizing MOSFETs to create

three-phase power through the motor. We will be using a 14.8V battery and ESC’s that are rated

for 2-40A to vary the speed of rotation. The microcontroller sends a PWM signal to the ESC to

control the speed of our Brushless motor from our battery. This is important as the ESC role in

our project is to control maneuvering and thrust while in flight.

Component Specs:

Voltage Supplied: 14.8v

Current Supplied: 10-40A

Brushless Motors

Our MARI drone will have brushless motors as they offer higher efficiency from the

reduced friction from brushed motors. We connect our motors to the ESC that sends power in

three phases which drives rotation in our motor. We plan on utilizing the Emax ECO II Series

1300KV brushless motor to generate over 1000 grams of force per motor at 315 watts. We will

be supplying 14.8v to the Brushless Motors between 2 - 40A which the ESC will handle in

addition to the rotational speed of our motors.

Component Specs:

Voltage Supplied: 14.8v

Current Supplied: 10-40A

### Software (Operating System):

The main purpose of the software is to stabilize the drone by regulating the signals sent

out to the ESCs/motors so the drone keeps an orientation that keeps it in the air. To achieve this,

it takes the data from the RF receiver, IMU, and barometer. The data from the RF receiver allows

the user to control the drone, while the data from the IMU and the barometer keeps the drone

stable.

The RTOS ensures this by separating all of these functions as separate tasks efficiently.

There is also an additional task that will collect and log data from the IMU and barometer to the

flash memory. There is also the occasional check for the voltage in the LED Warning Light task.

Ideally, these tasks would run in parallel as shown in the flowchart below


However, since this is a single-core processor, it can only run one task at a time.

Therefore these tasks will be switched in a very fast and efficient way through the task scheduler

that they will appear to run concurrently.

Bootup:

Programmer: ST-Link SWJ-DP (JTAG or SWD)

System Bootloader Peripheral: USART1

Tools: STM32CubeIDE

When the MCU on the drone first powers up or resets, it begins by checking the BOOT

pins/option bytes to decide where to start execution. In the normal case (BOOT0 = 0), it fetches

the initial stack pointer and reset vector from the start of Flash memory and begins running the

user bootloader, which then verifies and hands off to the main RTOS and flight software. If

BOOT0 = 1, the chip instead enters the built-in System Bootloader stored in ROM, which allows

programming or recovery over a USART interface. In either path, the MCU initializes its clocks,

regulators, and peripherals, then proceeds into the application code, ready to run the flight stack.

After the initial bootup, the drone will enter one of three operating modes: RUN, STOP,

and STANDBY. STOP mode is where most parts of the MCU are powered down, however it

retains all SRAM and registers. It only “wakes up” to RUN from an external interrupt such as the

RF Controller. STANDBY is a near total “dormancy” mode where nearly all parts are powered

down, including the registers and SRAM. It can only “wake up” from a WKUP pin, then

afterwards the software will reinitialize all registers.

All code needed for the bootup sequence is automatically generated by STM32CubeIDE

and stored into flash memory.

Operating System (MIKU)

The drone software runs on a custom RTOS called the Multi-Integrated Kernel Unit

(MIKU) where separate tasks handle sensing, control, and safety. Hardware events from the

IMU, barometer, RF receiver, and power monitor trigger interrupts that wake the appropriate

tasks via semaphores. These tasks communicate through shared data structures such as

CurrentDroneStates, Altitude, RC_Commands, and Flight Mode, which together describe the

drone’s current state and how it should behave.

The IMU generates periodic interrupts that wake the IMU Task. This task simply records

the current state of the drone based on IMU data and writes it into the CurrentDroneStates

structure. That state includes roll, pitch, and yaw angles, their angular rates, and

acceleration/direction data. The IMU Task does not perform control itself; it just ensures that the

rest of the system always has fresh motion data.

The barometer triggers the Baro Task through its interrupt. The Baro Task reads the

barometric pressure, computes the current altitude, and stores this in the Altitude data structure.

It also checks whether the measured altitude is higher than the configured safety altitude. If it is,

the Baro Task forces the altitude data so that the controller will drive the drone back toward that

safe altitude, ensuring the drone never stays above the allowed height.

Radio commands from the pilot are handled by the RF hardware and RC Task. The RF

interrupt wakes the RC Task, which decodes the packet and updates the RC_Commands structure

with the latest throttle, pitch, roll, yaw, and auxiliary switch positions. The Flight Mode flag

determines whether the system is in manual or automatic flight. In manual flight, the PID Task is

allowed to use RC_Commands directly to move the drone as the pilot intends. In automatic

flight, the PID Task ignores RC_Commands and relies only on internal logic, such as target or

safe altitude, to control the drone.

The radio receiver input will take the input from the user who will control throttle/pitch/roll/yaw

using the radio controller, which will be translated to individual signals given the following

equations:

Motor1: Front Left = throttle - roll - pitch + yaw

Motor2: Front Right = throttle + roll - pitch - yaw

Motor3 Rear Right = throttle + roll + pitch + yaw

Motor4: Rear Left = throttles - roll + pitch - yaw

To adjust for error, we will be implementing PID (Proportional Integral Derivative)

equations to adjust the roll, pitch, and yaw data from the IMU.

Within the RTOS, these equations are implemented inside the PID Task. At each control tick, the

PID Task reads CurrentDroneStates, Altitude, RC_Commands (if Flight Mode is manual), and

the Flight Mode flag. It computes the error between the desired attitude/altitude and the

measured values and then applies PID control. Here, u(t) is the adjustment we are making to the

commands sent to the motors, e(t) is the amount of error between the intended input from the

user and the actual data from the sensor, and Kp, Ki, and Kd are tunable hyperparameters. This

PID control signal is then added to the throttle/pitch/roll/yaw commands in the motor equations

above. Using those adjusted values, the PID Task generates the PWM signals to the motor ESCs,

increasing or decreasing their duty cycles to self-stabilize the drone while still tracking the pilot’s

intent when manual control is allowed.

The Warning LED Task is responsible for reacting to low-power conditions. When the

voltage-monitoring circuit detects that the battery is low, it triggers an interrupt that wakes the

Warning LED Task. This task turns on the appropriate LED pattern and also forces Flight Mode

to automatic flight while setting the safe altitude to 0 (ground level). With these changes, the PID

Task begins commanding a descent to altitude 0 and will not accept any new RF controls from

RC_Commands. This guarantees that once a critical power condition is detected, the drone

performs a safe, automatic landing under RTOS control.

Full Software Flow:


### Citations:

Hanewich, Tim. “How I Developed the Scout Flight Controller, Part 1: Quadcopter Flight

Dynamics.” Medium, Medium, 31 July 2023,

timhanewich.medium.com/how-i-developed-the-scout-flight-controller-part-1-quadcopter-f

light-dynamics-400af73d21db.

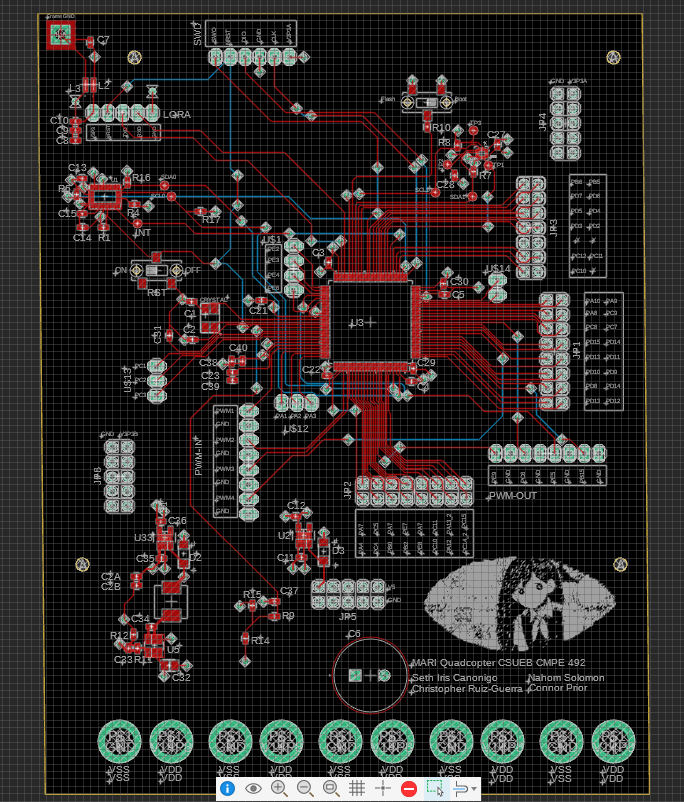
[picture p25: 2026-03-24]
design/hardware/MARI_PCB_Layout_Top.png

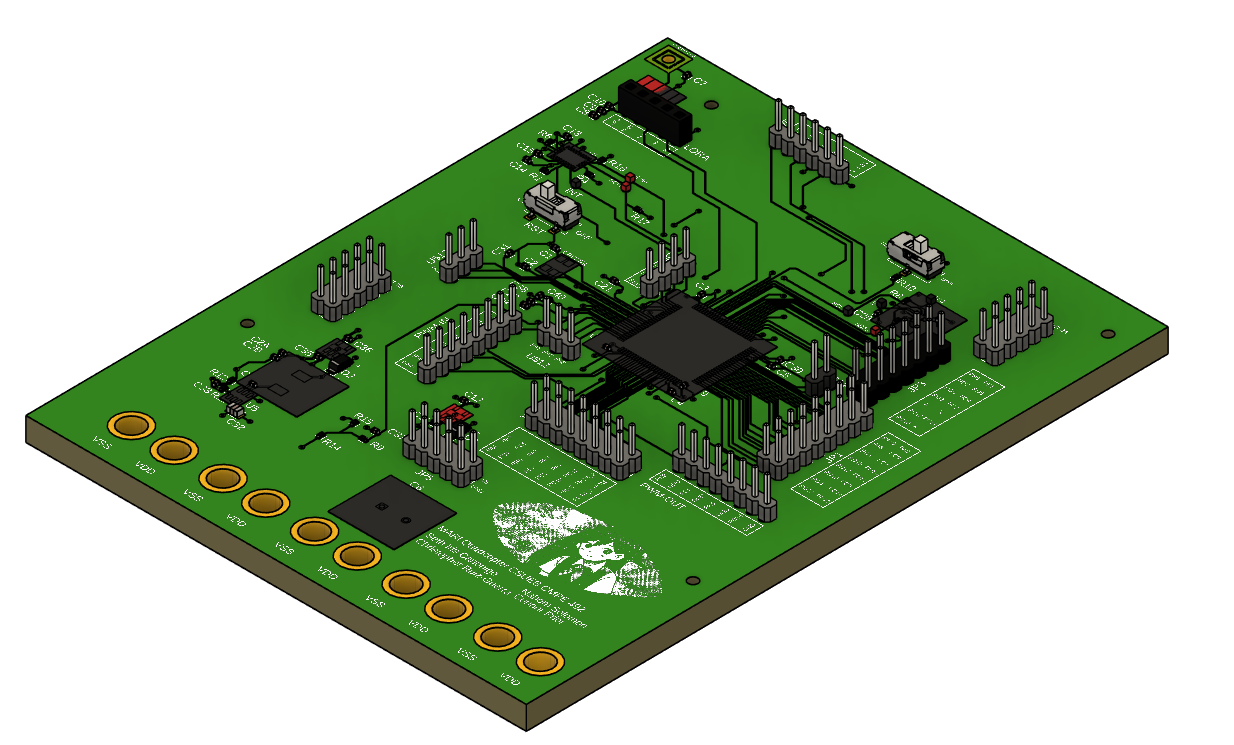
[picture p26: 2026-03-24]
design/hardware/MARI_PCB_3D_Isometric.png

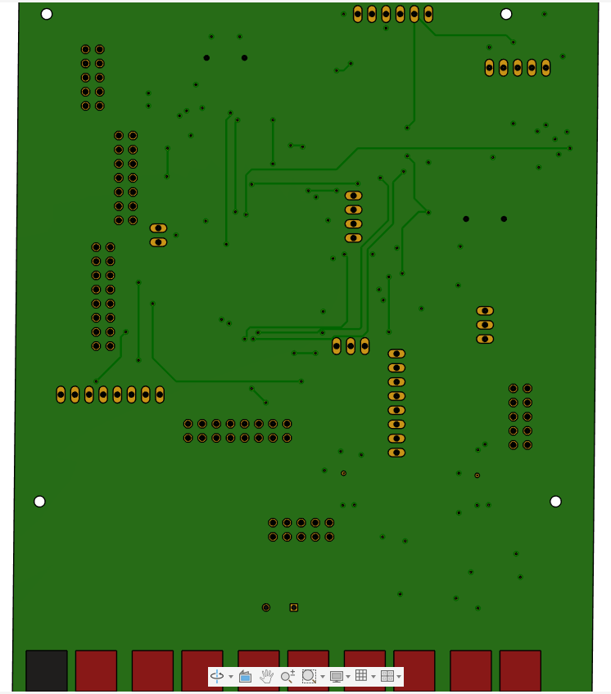
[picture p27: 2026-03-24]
design/hardware/MARI_PCB_3D_Bottom.png

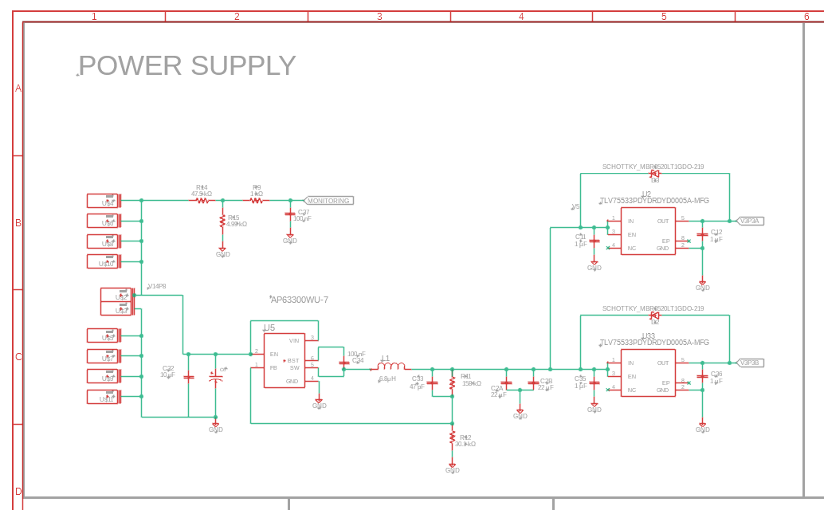
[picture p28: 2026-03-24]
design/hardware/MARI_PDN_Schematic_V2.png

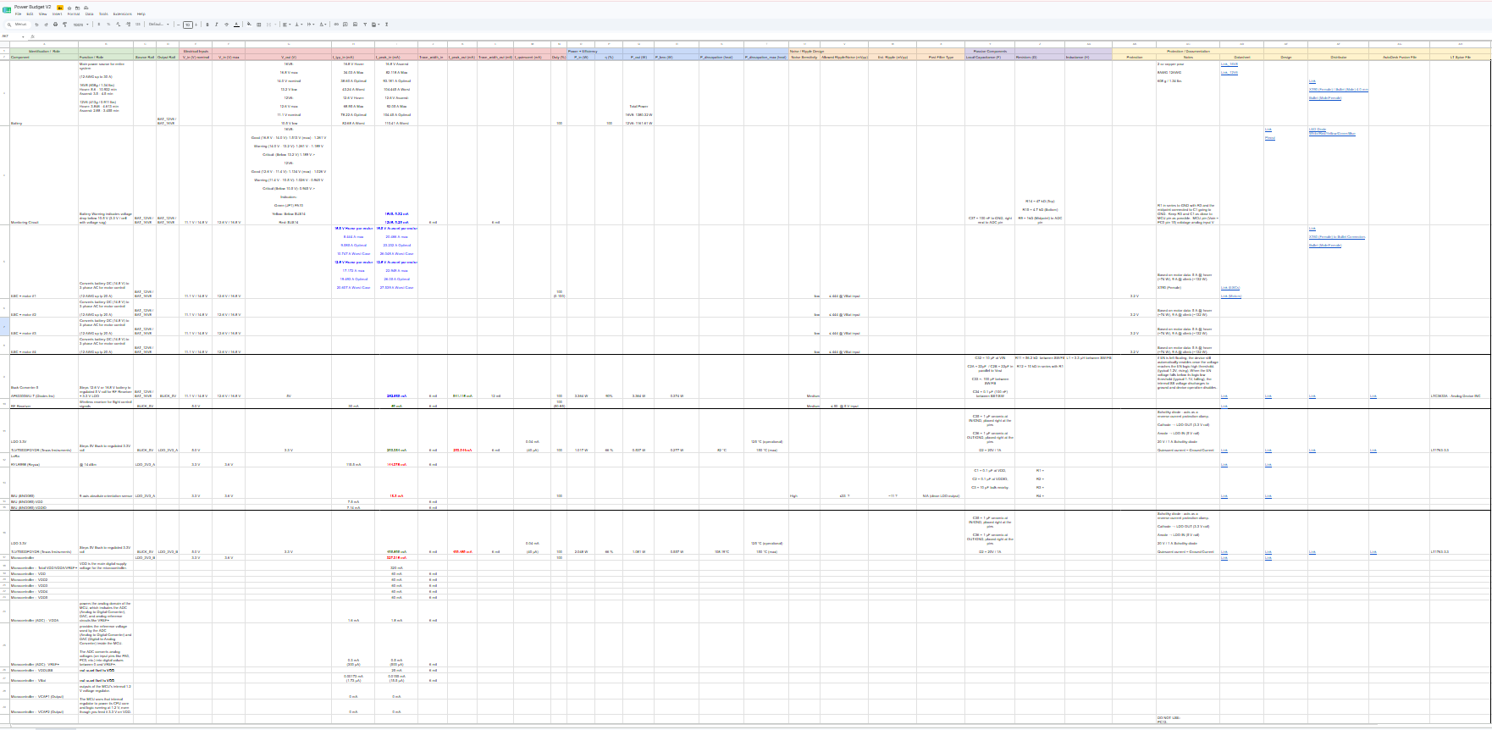
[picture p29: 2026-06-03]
analysis/power_budget/screenshots/Power Budget V2 screenshot.png

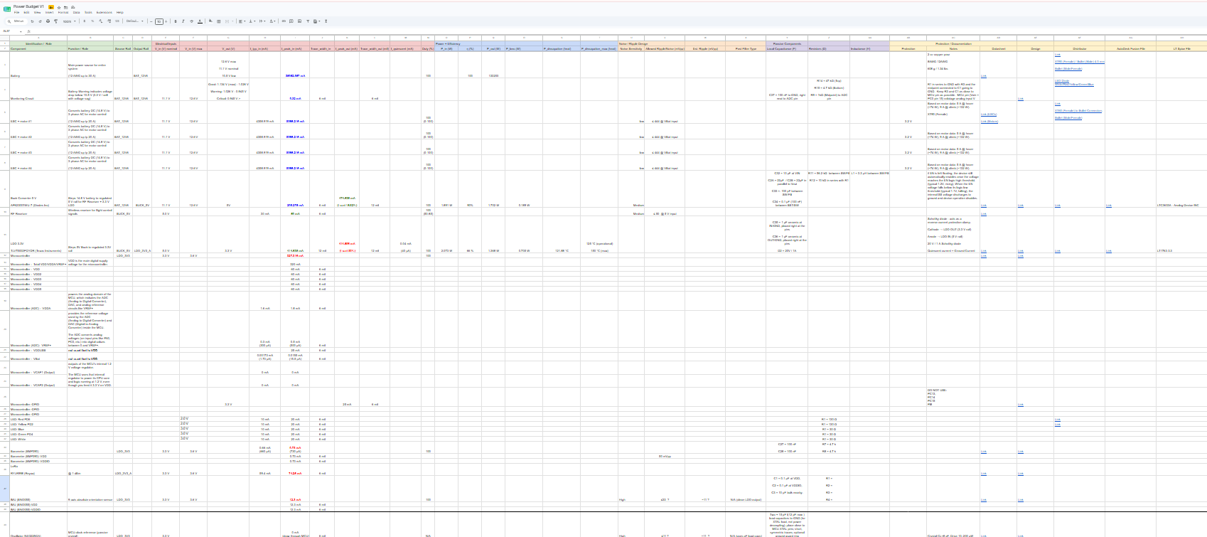
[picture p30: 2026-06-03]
analysis/power_budget/screenshots/Power Budget V1 screenshot.png

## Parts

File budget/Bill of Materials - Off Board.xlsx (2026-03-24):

Off PCB
Name | Quantity | Price Per Unit ($) | Total Price ($) | Link
CNHL 6200mAh 14.8V 4S 30C Lipo Battery with XT90 Plug Lipo Battery with XT90 Plug | 2 | 59.99 | 119.98 | link (https://chinahobbyline.com/collections/cnhl-voltage-14-8v-4s-lipo-batteries/products/cnhl-6200mah-14-8v-4s-30c-lipo-battery-with-xt90-plug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)
Bistook XT90 to 4mm Bullet Plug Male/Female, 12AWG (Battery-PCB) | 1 | 8.99 | 8.99 | link (https://www.amazon.com/connectors-centimeters-Lithium-Battery-Charging/dp/B0DHKCSBWZ)
Genuine AMASS Nylon XT90 Male / Female Connectors with End Cap | 1 | 5.49 | 5.49 | link (https://rcbattery.com/nylon-xt90-male-female-connectors-with-end-cap-5-sets.html?gad_source=1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)
10 Gauge Silicone Wire (2 PCS) 10 FT Red + 10 FT Black Tinned Copper Core, Flexible 10 AWG High Temp Wire for Battery, Automotive, Solar, RC Car, Drones etc. | 1 | 17.99 | 17.99 | link (https://www.amazon.com/Silicone-Tinned-Flexible-Battery-Automotive/dp/B0F7XKB59J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)
2pcs XT60H (XT60 Upgarded Female Connector Plug to 4mm Banana Plugs Battery Charge Lead Adapter Cable 12awg 30cm (ESCs-PCB) | 2 | 8.99 | 17.98 | link (https://www.amazon.com/Upgarded-Female-Connector-Battery-Adapter/dp/B0CMZSLDBG)
4.0mm Male Female Banana Plug Bullet Connector Adapter for RC Lipo Battery ESC Motors 20 set (PCB) | 1 | 9.99 | 9.99 | link (https://www.amazon.com/Yiqigou-Gold-Plated-Banana-Connector-Battery/dp/B07PP7DD3T)
Gemfan LR 7035 2-Blade Propeller (4 Set) | 2 | 5.49 | 10.98 | link (https://www.getfpv.com/gemfan-lr-7035-2-blade-propeller-set-of-4-5mm-white.html)
Emax ECO II Series 2807-1300KV Motor | 4 | 26.16 | 104.64 | link (https://emaxmodel.com/products/emax-eco-ii-series-2807-1300kv-1700kv-1500kv-brushless-motor-for-rc-drone-fpv-racing)
30A RC Brushless Motor Electric Speed Controller ESC 3A UBEC with XT60 & 3.5mm Bullet Plugs | 4 | 17.99 | 71.96 | link (https://www.amazon.com/gp/product/B071GRSFBD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)
LED Diode White/Red/Yellow/Green/Blue | 1 | 11.99 | 11.99 | link (https://www.amazon.com/DiCUNO-450pcs-Colors-Emitting-Assorted/dp/B073QMYKDM)

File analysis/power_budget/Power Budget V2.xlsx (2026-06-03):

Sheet: Power Budget
Identification / Role |  |  |  | Electrical Inputs |  |  |  |  |  |  |  |  |  | Power + Efficiency |  |  |  |  |  | Noise / Ripple Design |  |  |  | Passive Components |  |  | Protection / Documentation
Component | Function / Role | Source Rail | Output Rail | V_in (V) nominal | V_in (V) max | V_out (V) | I_typ_in (mA) | I_peak_in (mA) | Trace_width_in | I_peak_out (mA) | Trace_width_out (mil) | I_quiescent (mA) | Duty (%) | P_in (W) | η (%) | P_out (W) | P_loss (W) | P_dissapation (heat) | P_dissapation_max (heat) | Noise Sensitivity | Allowed Ripple/Noise (mVpp) | Est. Ripple (mVpp) | Post-Filter Type | Local Capacitance (F) | Resistors (Ω) | Inductance (H) | Protection | Notes | Datasheet | Design | Distributor | AutoDesk Fusion File | LT Spice File
Battery | Main power source for entire system (12 AWG up to 30 A) 16V8 (608g / 1.34 lbs) Hover: 8.6 - 10.932 min Ascend: 3.5 - 4.5 min 12V6 (413g / 0.911 lbs) Hover: 3.846 - 4.613 min Ascend: 2.88 - 3.455 min |  | BAT_12V6 / BAT_16V8 |  |  | 16V8: 16.8 V max 14.0 V nominal 13.2 V low 12V6: 12.6 V max 11.1 V nominal 10.5 V low | 16.8 V Hover 34.03 A Max 38.60 A Optimal 43.24 A Worst 12.6 V Hover: 68.95 A Max 78.22 A Optimal 82.68 A Worst | 16.8 V Ascend 82.118 A Max 93.181 A Optimal 104.445 A Worst 12.6 V Ascend: 92.05 A Max 104.45 A Optimal 110.41 A Worst |  |  |  |  | 100 |  | 100 | Total Power 16V8: 1380.32 W 12V6: 1161.61 W |  |  |  |  |  |  |  |  |  |  |  | 2 oz copper pour 8AWG-12AWG 608 g / 1.34 lbs | Link_16V8 Link_12V6 (https://chinahobbyline.com/collections/cnhl-voltage-14-8v-4s-lipo-batteries/products/cnhl-6200mah-14-8v-4s-30c-lipo-battery-with-xt90-plug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) |  | Link XT90 (Female) / Bullet (Male) 4.0 mm Bullet (Male/Female) (https://chinahobbyline.com/collections/cnhl-voltage-14-8v-4s-lipo-batteries/products/cnhl-6200mah-14-8v-4s-30c-lipo-battery-with-xt90-plug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)
Monitoring Circuit | Battery Warning indicates voltage drop below 10.5 V (3.3 V / cell with voltage sag) | BAT_12V6 / BAT_16V8 | BAT_12V6 / BAT_16V8 | 11.1 V / 14.8 V | 12.6 V / 16.8 V | 16V8: Good (16.8 V - 14.0 V): 1.513 V (max) - 1.261 V Warning (14.0 V - 13.2 V): 1.261 V - 1.189 V Critical: (Below 13.2 V) 1.189 V > 12V6: Good (12.6 V - 11.4 V): 1.134 V (max) - 1.026 V Warning (11.4 V - 10.5 V): 1.026 V - 0.945 V Critical (Below 10.5 V): 0.945 V > Indicators: Green (JP1) PA10 Yellow: Below $US14 Red: $US14 |  | 16V8: 0.32 mA 12V6: 0.29 mA | 6 mil |  | 6 mil |  |  |  |  |  |  |  |  |  |  |  |  | C37 = 100 nF to GND, right next to ADC pin | R14 = 47 kΩ (Top) R15 = 4.7 kΩ (Bottom) R9 = 1kΩ (Midpoint) to ADC pin |  |  | R1 in series to GND with R3 and the midpoint connected to C1 going to GND. Keep R3 and C1 as close to MCU pin as possible. MCU pin (Vain = PC0 pin 15) volatage analog input V |  | Link Pinout (https://docs.google.com/document/d/13BQ7PQnixL5HRD4vcnCwSoZ17bO2JmQ23-hnail3f_I/edit?tab=t.0) | LED Diode White/Red/Yellow/Green/Blue (https://www.amazon.com/DiCUNO-450pcs-Colors-Emitting-Assorted/dp/B073QMYKDM)
ESC + motor #1 | Converts battery DC (14.8 V) to 3-phase AC for motor control (12 AWG up tp 20 A) | BAT_12V6 / BAT_16V8 |  | 11.1 V / 14.8 V | 12.6 V / 16.8 V |  | 16.8 V Hover per motor 8.444 A max 9.585 A Optimal 10.747 A Worst Case 12.6 V Hover per motor 17.172 A max 19.493 A Optimal 20.607 A Worst Case | 16.8 V Ascend per motor 20.466 A max 23.232 A Optimal 26.048 A Worst Case 12.6 V Ascend per motor 22.949 A max 26.05 A Optimal 27.539 A Worst Case |  |  |  |  | 100 (0-100) |  |  |  |  |  |  | low | ≤ 444 @ VBat input |  |  |  |  |  | 3.2 V | Based on motor data: 5 A @ hover (~74 W), 9 A @ climb (~132 W). XT90 (Female) | Link (ESCs) Link (Motors) (https://www.amazon.com/RC-Brushless-Electric-Controller-bullet/dp/B0754H7XZZ?th=1) |  | Link XT60 (Female) to Bullet Connectors Bullet (Male/Female) (https://www.amazon.com/RC-Brushless-Electric-Controller-bullet/dp/B0754H7XZZ?th=1)
ESC + motor #2 | Converts battery DC (14.8 V) to 3-phase AC for motor control (12 AWG up tp 20 A) | BAT_12V6 / BAT_16V8 |  | 11.1 V / 14.8 V | 12.6 V / 16.8 V |  |  |  |  |  |  |  |  |  |  |  |  |  |  | low | ≤ 444 @ VBat input |  |  |  |  |  | 3.2 V | Based on motor data: 5 A @ hover (~74 W), 9 A @ climb (~132 W).
ESC + motor #3 | Converts battery DC (14.8 V) to 3-phase AC for motor control (12 AWG up tp 20 A) | BAT_12V6 / BAT_16V8 |  | 11.1 V / 14.8 V | 12.6 V / 16.8 V |  |  |  |  |  |  |  |  |  |  |  |  |  |  | low | ≤ 444 @ VBat input |  |  |  |  |  | 3.2 V | Based on motor data: 5 A @ hover (~74 W), 9 A @ climb (~132 W).
ESC + motor #4 | Converts battery DC (14.8 V) to 3-phase AC for motor control (12 AWG up tp 20 A) | BAT_12V6 / BAT_16V8 |  | 11.1 V / 14.8 V | 12.6 V / 16.8 V |  |  |  |  |  |  |  |  |  |  |  |  |  |  | low | ≤ 444 @ VBat input |  |  |  |  |  | 3.2 V | Based on motor data: 5 A @ hover (~74 W), 9 A @ climb (~132 W).
Buck Converter 5 AP63300WU-7 (Diodes Inc) | Steps 12.6 V or 16.8 V battery to regulated 5 V rail for RF Receiver + 3.3 V LDO | BAT_12V6 / BAT_16V8 | BUCK_5V | 11.1 V / 14.8 V | 12.6 V / 16.8 V | 5V |  | 252.588 mA | 6 mil | 841.116 mA | 12 mil |  | 100 | 3.364 W | 90% | 3.364 W | 0.374 W |  |  | Medium |  |  |  | C32 = 10 µF at VIN C2A = 22µF / C2B = 22µF in parallel to Vout C33 =. 100 pF between SW/FB C34 = 0.1 µF (100 nF) between BST/SW | R11 = 56.2 kΩ between SW/FB R12 = 10 kΩ in series with R1 | L1 = 3.3 µH between SW/FB |  | if EN is left floating, the device still automatically enables once the voltage reaches the EN logic high threshold. (typical 1.2V, rising), When the EN voltage falls below its logic low threshold (typical 1.1V, falling), the internal SS voltage discharges to ground and device operation disables. | Link (https://drive.google.com/drive/u/0/folders/1v3HOcfDkCG08hydkAwiFy88Z6sSVDIoy) | Link (https://docs.google.com/document/d/16EDnAHiTcgNvPhUuXfGpH5qLadYG68Q37WCe-nAsvZ8/edit?tab=t.0) | Link (https://www.digikey.com/en/products/detail/diodes-incorporated/AP63300WU-7/10491510) | Link (https://drive.google.com/drive/u/0/folders/1a5-4cdKhiVMgbkTae8DDaRTtWuyIa1Bq) | LTC3633A - Analog Device INC
RF Receiver | Wireless receiver for flight control signals | BUCK_5V |  | 5.0 V |  |  | 30 mA | 60 mA | 6 mil |  |  |  | 100 (50-85) |  |  |  |  |  |  | Medium | ≤ 50 @ 5 V input |  |  |  |  |  |  |  | Link (https://drive.google.com/drive/folders/17Tw_hd8-7eAD8DBklDislGriO99LYTNb)
LDO 3.3V TLV75533PDYDR (Texas Instruments) | Steps 5V Buck to regulated 3.3V rail | BUCK_5V | LDO_3V3_A | 5.0 V |  | 3.3 V |  | 203.384 mA | 6 mil | 203.344mA | 6 mil | 0.04 mA (40 µA) | 100 | 1.017 W | 66 % | 0.537 W | 0.277 W | 82 °C | 125 °C (operational) 150 °C (max) |  |  |  |  | C35 = 1 µF ceramic at IN/GND, placed right at the pins C36 = 1 µF ceramic at OUT/GND, placed right at the pins D2 = 20V / 1A |  |  |  | Schottky diode - acts as a reverse-current protection clamp. Cathode → LDO OUT (3.3 V rail) Anode → LDO IN (5 V rail) 20 V / 1 A Schottky diode Quiescent current = Ground Current | Link (https://drive.google.com/drive/u/0/folders/1ij7AUYx8Fi4RG1AMtG-WFDpLnHO8msBU) | Link (https://docs.google.com/document/d/1oEgNGvVG_-55sK4kfF59cSOM-K30eRwwsokSswShEp4/edit?tab=t.0) | Link (https://www.digikey.com/en/products/detail/texas-instruments/TLV75533PDYDR/22531567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) | Link (https://drive.google.com/drive/u/0/folders/1_81v0_oRvqxmoDHrnWV0DEFLloFRnqxm) | LT1763-3.3
LoRa RYLR998 (Reyax) | @ 14 dBm | LDO_3V3_A |  | 3.3 V | 3.6 V |  | 115.5 mA | 144.375 mA | 6 mil |  |  |  |  |  |  |  |  |  |  |  |  |  |  |  |  |  |  |  | Link (https://drive.google.com/drive/folders/13K0B-ypS7Gk6d7YwSrRNKJfsF120EFao) | Link (https://docs.google.com/document/d/1ONgtAqB95VsvPedvpWRmap_yJkLvS0_XCnZ9lVkM3zE/edit?tab=t.0)
IMU (BNO085) | 9-axis absolute orientation sensor | LDO_3V3_A |  | 3.3 V | 3.6 V |  |  | 18.3 mA |  |  |  |  | 100 |  |  |  |  |  |  | High | ≤33 ? | ~11 ? | N/A (clean LDO output) | C1 = 0.1 µF at VDD, C2 = 0.1 µF at VDDIO, C3 = 10 µF bulk nearby. | R1 = R2 = R3 = R4 = |  |  |  | Link (https://drive.google.com/drive/folders/1KouXzasUXyFXZFctQanwq-t4oPLXM069) | Link (https://docs.google.com/document/d/1NMmhh-Yh2119CAi3HEptOx2RkKPUScvKhlriqZeASBo/edit?tab=t.0)
IMU (BNO085):VDD |  |  |  |  |  |  | 7.5 mA |  | 6 mil
IMU (BNO085):VDDIO |  |  |  |  |  |  | 7.14 mA |  | 6 mil
LDO 3.3V TLV75533PDYDR (Texas Instruments) | Steps 5V Buck to regulated 3.3V rail | BUCK_5V | LDO_3V3_B | 5.0 V |  | 3.3 V |  | 409.509 mA | 6 mil | 409.469 mA | 6 mil | 0.04 mA (40 µA) | 100 | 2.048 W | 66 % | 1.081 W | 0.557 W | 108.19°C | 125 °C (operational) 150 °C (max) |  |  |  |  | C35 = 1 µF ceramic at IN/GND, placed right at the pins C36 = 1 µF ceramic at OUT/GND, placed right at the pins D2 = 20V / 1A |  |  |  | Schottky diode - acts as a reverse-current protection clamp. Cathode → LDO OUT (3.3 V rail) Anode → LDO IN (5 V rail) 20 V / 1 A Schottky diode Quiescent current = Ground Current | Link (https://drive.google.com/drive/u/0/folders/1ij7AUYx8Fi4RG1AMtG-WFDpLnHO8msBU) | Link (https://docs.google.com/document/d/1oEgNGvVG_-55sK4kfF59cSOM-K30eRwwsokSswShEp4/edit?tab=t.0) | Link (https://www.digikey.com/en/products/detail/texas-instruments/TLV75533PDYDR/22531567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) | Link (https://drive.google.com/drive/u/0/folders/1_81v0_oRvqxmoDHrnWV0DEFLloFRnqxm) | LT1763-3.3
Microcontroller |  | LDO_3V3_B |  | 3.3 V | 3.6 V |  |  | 327.316 mA |  |  |  |  | 100 |  |  |  |  |  |  |  |  |  |  |  |  |  |  |  | Link (https://drive.google.com/drive/folders/18ZPus5rWx-Za64Z5Ci7vNzVwEuhcWyIr) | Link (https://docs.google.com/document/d/1uBLUYh11gR3F2JG5l_bQqe_JnSmMHNd37-J3TzYSs0s/edit?tab=t.0)
Microcontroller : Total VDD/VDDA/VREF+ | VDD is the main digital supply voltage for the microcontroller. |  |  |  |  |  |  | 320 mA
Microcontroller : VDD |  |  |  |  |  |  |  | 60 mA | 6 mil
Microcontroller : VDD2 |  |  |  |  |  |  |  | 60 mA | 6 mil
Microcontroller : VDD3 |  |  |  |  |  |  |  | 60 mA | 6 mil
Microcontroller : VDD4 |  |  |  |  |  |  |  | 60 mA | 6 mil
Microcontroller : VDD5 |  |  |  |  |  |  |  | 60 mA | 6 mil
Microcontroller (ADC) : VDDA | powers the analog domain of the MCU, which includes the ADC (Analog-to-Digital Converter), DAC, and analog reference circuits like VREF+ |  |  |  |  |  | 1.6 mA | 1.8 mA | 6 mil
Microcontroller (ADC): VREF+ | provides the reference voltage used by the ADC (Analog-to-Digital Converter) and DAC (Digital-to-Analog Converter) inside the MCU. The ADC converts analog voltages (on input pins like PA0, PC0, etc.) into digital values between 0 and VREF+. |  |  |  |  |  | 0.3 mA (300 µA) | 0.5 mA (500 µA) | 6 mil
Microcontroller : VDDUSB | not used tied to VDD |  |  |  |  |  |  | 25 mA | 6 mil
Microcontroller : VBat | not used tied to VDD |  |  |  |  |  | 0.00173 mA (1.73 µA) | 0.0155 mA (15.5 µA) | 6 mil
Microcontroller : VCAP1 (Output) | outputs of the MCU’s internal 1.2 V voltage regulator. The MCU uses that internal regulator to power its CPU core and logic running at 1.2 V, even though you feed it 3.3 V on VDD. |  |  |  |  |  | 0 mA | 0 mA
Microcontroller : VCAP2 (Output) |  |  |  |  |  |  | 0 mA | 0 mA
Microcontroller: GPIO |  |  |  |  |  | 3.3 V |  |  |  | 25 mA | 6 mil |  |  |  |  |  |  |  |  |  |  |  |  |  |  |  |  | DO NOT USE: PC13, PC14 PC15 PI8 |  | Link (https://docs.google.com/document/d/186rYK0YnsifaJs2RieBhUgeNdw8-rii_Ggdu0bvtwEw/edit?tab=t.0)
Microcontroller: GPIO
Microcontroller: GPIO
LED: Red PD6 |  |  |  |  | 2.0 V |  | 10 mA | 20 mA | 6 mil |  |  |  |  |  |  |  |  |  |  |  |  |  |  |  | R1 = 130 Ω |  |  |  |  |  | Link (https://www.amazon.com/DiCUNO-450pcs-Colors-Emitting-Assorted/dp/B073QMYKDM)
LED: Yellow PD2 |  |  |  |  | 2.0 V |  | 10 mA | 20 mA | 6 mil |  |  |  |  |  |  |  |  |  |  |  |  |  |  |  | R1 = 130 Ω |  |  |  |  |  | Link (https://www.amazon.com/DiCUNO-450pcs-Colors-Emitting-Assorted/dp/B073QMYKDM)
LED: Blue |  |  |  |  | 3.0 V |  | 10 mA | 20 mA | 6 mil |  |  |  |  |  |  |  |  |  |  |  |  |  |  |  | R1 = 30 Ω
LED: Green PD4 |  |  |  |  | 3.0 V |  | 10 mA | 20 mA | 6 mil |  |  |  |  |  |  |  |  |  |  |  |  |  |  |  | R1 = 30 Ω
LED: White |  |  |  |  | 3.0 V |  | 10 mA | 20 mA | 6 mil |  |  |  |  |  |  |  |  |  |  |  |  |  |  |  | R1 = 30 Ω
Oscillator (NX3225GA) | MCU clock reference (passive crystal) | LDO_3V3_B |  | 3.3 V |  |  |  | 0 mA (draw through MCU) | 6 mil |  |  |  | N/A |  |  |  |  |  |  | High | ≤11 ? | ~11 ? | N/A (uses pF load caps) | Two ≈ 15 pF l(12 pF-now ) load capacitors to GND (for XTAL load, not power decoupling); place close to MCU XTAL pins; short, symmetric traces; optional ground guard ring |  |  |  | Crystal CL=8 pF, Drive 10–200 µW | Link (https://drive.google.com/drive/folders/1SeZpFCq1jOZTPZZtfmEA3qCv648KZdC8) | Link (https://docs.google.com/document/d/1k4ZxfbQkCt_RZczf__P-YZC0v3f92IhxXLAHnAe69PE/edit?tab=t.0)
Barometer (BMP581) |  | LDO_3V3_B |  | 3.3 V | 3.6 V |  |  | 0.26 mA (260 µA) |  |  |  |  | 100 |  |  |  |  |  |  |  |  |  |  | C27 = 100 nF C28 = 100 nF | R7 = 4.7 k R8 = 4.7 k |  |  |  | Link (https://drive.google.com/drive/folders/16PqZMUmhjEajuRPCSwPU6lDnbKGAXtiw) | Link (https://docs.google.com/document/d/1eKAsBc72HkK4ubr__D_FUMPEZeg3ejlmYCY3Pa8npkQ/edit?tab=t.0)
Barometer (BMP581): VDD |  |  |  |  |  |  |  |  | 6 mil |  |  |  |  |  |  |  |  |  |  |  | 50 mVpp
Barometer (BMP581): VDDIO |  |  |  |  |  |  |  |  | 6 mil
Bill of Material (BOM) (https://docs.google.com/spreadsheets/d/1d4GywLl9_E9B6HAGy_M0x8jvDwejFZVBtnJ3f2Tjn1I/edit?gid=0)
https://www.advancedpcb.com/en-us/tools/trace-width-calculator/
-
https://tracewidthcalculator.com/
 | Temperature Rise | 10
 | Ambient Temp | 25
 | Copper | 1 oz
mVpp = millivolts peak-to-peak
Allowed Ripple / Noise | The maximum voltage fluctuation that the device can safely tolerate on its supply without malfunctioning. (This is your design limit.) |  |  |  |  |  |  |  |  |  |  |  | From rail → device
Estimated Ripple / Noise | The actual expected ripple on that supply rail once your regulator + caps + layout are in place. (What the device will “see.”) |  |  |  |  |  |  |  |  |  |  |  | From rail → device
Local capacitance | tells you how much capacitance you have (the numbers).
Local decoupling | tells you how you’re using and placing it.

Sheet: New Components
Domain: 16.8 V
Item # | *Ref Des | Qty per Board | *Qty | Manufacturer | *Mfg Part # | Description / Value | *Package | Voltage - Rated | Current - Rated | Power - Rated | Type | Your Instructions / Notes | Unit Cost | Total Cost | Website
1 | C32 | 1 | 1 | Murata Electronics | GRM21BR61H106KE43L | Capacitor 10 uF | 805 | 50 V |  |  | Surface Mount |  | 0.3 | 0.3 | link (https://www.digikey.com/en/products/detail/murata-electronics/GRM21BR61H106KE43L/10326316)
2 | U$55 | 1 | 1 | Diodes Inc. | AP62300TWU-7 | 5 V Buck Converter | SOT-23-6 Thin | 18 V |  |  | Surface Mount |  | 0.3 | 0.3 | link (https://www.digikey.com/en/products/detail/diodes-incorporated/AP62300TWU-7/12702558)
 |  | 1 |  |  |  | Capacitor 1000 uF |  | 35V |  |  | Surface Mount
 |  |  |  |  |  | Capacitor 470 uF |  | 35V |  |  | Surface Mount
Domain: 5V
Item # | *Ref Des | Qty per Board | *Qty | Manufacturer | *Mfg Part # | Description / Value | *Package | Voltage - Rated | Current - Rated | Power - Rated | Type | Your Instructions / Notes | Unit Cost | Total Cost | Website
3 | C34 | 1 | 1 | Samsung Electromechanics | CL05A104KA5NNNC | Capacitor 100nF | 402 | 25V |  |  | Surface Mount |  | 0.1 | 0.1 | link (https://www.digikey.com/en/products/detail/samsung-electro-mechanics/CL05A104KA5NNNC/3886701)
4 | L1 | 1 | 1 | Murata Electronics | LQM21PN3R3MGRD | Inductor 3.3 µH | 805 |  | 1A |  | Surface Mount |  | 0.17 | 0.17 | link (https://www.digikey.com/en/products/detail/murata-electronics/LQM21PN3R3MGRD/4359175)
5 | C33 | 1 | 1 | YAGEO | CC0402JRNPO9BN101 | Capacitor 100 pF | 402 | 50 V |  |  | Surface Mount |  | 0.08 | 0.08 | link (https://www.digikey.com/en/products/detail/yageo/CC0402JRNPO9BN101/302758)
6 | R11 | 1 | 1 | Panasonic Electronic Components | ERJ-2RKF5622X | Resistors 56.2k | 402 |  |  | 0.1 W | Surface Mount |  | 0.1 | 0.1 | link (https://www.digikey.com/en/products/detail/panasonic-electronic-components/ERJ-2RKF5622X/192409)
7 | R12 | 1 | 1 | Samsung Electromechanics | RC1005F103CS | Resistors 10k | 402 |  |  | 0.063 W | Surface Mount |  | 0.1 | 0.1 | link (https://www.digikey.com/en/products/detail/panasonic-electronic-components/ERA-2AEB103X/1706029)
8 | C2A,C2B | 2 | 2 | Samsung Electromechanics | CL21A226MOQNNNE | Capacitor 22 µF | 805 | 16V |  |  | Surface Mount |  | 0.27 | 0.54 | link (https://www.digikey.com/en/products/detail/samsung-electro-mechanics/CL21A226MOQNNNE/3888567)
Domain: 3.3V
Item # | *Ref Des | Qty per Board | *Qty | Manufacturer | *Mfg Part # | Description / Value | *Package | Voltage - Rated | Current - Rated | Power - Rated | Type | Your Instructions / Notes | Unit Cost | Total Cost | Website
9 | U33 | 1 | 1 | Texas Instruments | TLV75533PDYDR | 3.3 V LDO | SC-74A | 5.5 V |  |  | Surface Mount |  | 0.29 | 0.29 | link (https://www.digikey.com/en/products/detail/texas-instruments/TLV75533PDYDR/22531567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)
10 | C35, C36 | 2 | 2 | Samsung Electromechanics | CL05A105KP5NNNC | Capacitor 1uF | 402 | 10V |  |  | Surface Mount |  | 0.1 | 0.2 | link (https://www.digikey.com/en/products/detail/samsung-electro-mechanics/CL05A105KP5NNNC/3886734)
13 | D2 | 1 | 1 | MCC (Micro Commercial Components) | SM5817PL-TP | Schottky Diode | SOD-123 | 20V | 1A |  | Surface Mount |  | 0.15 | 0.15 | link (https://www.digikey.com/en/products/detail/mcc-micro-commercial-components/SM5817PL-TP/1793251)
Bulk Cap
 |  |  |  |  |  |  | 50nH | 150 nH | 300 nH | 600 nH | 900 nH | 1200 nH | 1500 nH | Rankings
 | B41866C5108M000 (https://www.digikey.com/en/products/detail/epcos-tdk-electronics/B41866C5108M000/5844975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) |  | 1000 µF | 110m Ohm | 0.11 Ohm | 25V | 15.084 V | 13.45 V | 12.602 V | 12.61 V | 12.775 V | 12.975 V | 13.154 V | 1
 | EKYC250ELL821MJ16S (https://www.digikey.com/en/products/detail/chemi-con/ekyc250ell821mj16s/10486526) |  | 820 µF | 100m Ohm | 0.1 Ohm | 25V | 14.671 V | 13.107 V | 12.609 V | 12.717 V | 13.009 V | 13.261 V | 13.485 V | 2
 | EGXF250ELL751MJ16S (https://www.digikey.com/en/products/detail/chemi-con/EGXF250ELL751MJ16S/6204394) |  | 750 µF | 94m Ohm | 0.094 Ohm | 25V | 14.401 V | 12.904 V | 12.61 V | 12.827 V | 13.161 V | 13.445 V | 13.696 V | 3
 | EGXF250ELL911MK15S (https://www.digikey.com/en/products/detail/chemi-con/EGXF250ELL911MK15S/6204395) |  | 910 µF | 82m Ohm | 0.082 Ohm | 25V | 13.767 V | 12.608 V | 12.608 V | 12.799 V | 13.146 V | 13.443 V | 13.703 V | 4
 | B41858C5477M000 (https://www.digikey.com/en/products/detail/epcos-tdk-electronics/B41858C5477M000/3543592) |  | 470 µF | 118m Ohm | 0.118 Ohm | 25V | 15.455 V | 13.893 V | 12.986 V | 12.990 V | 13.323 V | 13.611 V | 13.863 V | 5

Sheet: Old Components
16.8 V
Item # | *Ref Des | *Qty | Manufacturer | *Mfg Part # | Description / Value | *Package | Voltage - Rated | Current - Rated | Power - Rated | Type | Your Instructions / Notes | Unit Cost | Total Cost | Website
9 | C32 | 1 | Samsung Electromechanics | GRM21BC81D106KE51L | Capacitor 10 uF | 805 | 20 V |  |  | Surface Mount |  | 0.24 | 0.24 | link (https://www.digikey.com/en/products/detail/murata-electronics/GRM21BC81D106KE51L/5027585)
34 | U$55 | 1 | Diodes Inc. | AP62300TWU-7 | 5 V Buck Converter | SOT-23-6 Thin | 18 V |  |  | Surface Mount |  | 0.3 | 0.3 | link (https://www.digikey.com/en/products/detail/diodes-incorporated/AP62300TWU-7/12702558)
5V
Item # | *Ref Des | *Qty | Manufacturer | *Mfg Part # | Description / Value | *Package |  |  |  | Type | Your Instructions / Notes | Unit Cost | Total Cost | Website
5 | C34 | 1 | Samsung Electromechanics | CL05A104KA5NNNC | Capacitor 100nF | 402 | 25V |  |  | Surface Mount |  | 0.09 | 0.09 | link (https://www.digikey.com/en/products/detail/samsung-electro-mechanics/CL05A104KA5NNNC/3886701)
21 | L1 | 1 | Bourns Inc. | CWF1610-3R3K | Inductor 3.3 µH | 603 |  | 500 mA |  | Surface Mount |  | 0.15 | 0.15 | link (https://www.digikey.com/en/products/detail/bourns-inc/CWF1610-3R3K/14644685)
10 | C33 | 1 | Wurth Electronik | 885012005013 | Capacitor 100 pF | 402 | 10V |  |  | Surface Mount |  | 0.1 | 0.1 | link (https://www.digikey.com/en/products/detail/w%C3%BCrth-elektronik/885012005013/5453286)
26 | R11 | 1 | Panasonic Electronic Components | ERJ-2RKF5622X | Resistors 56.2k | 402 |  |  | 0.1 W | Surface Mount |  | 0.1 | 0.1 | link (https://www.digikey.com/en/products/detail/panasonic-electronic-components/ERJ-2RKF5622X/192409)
22 | R12 | 1 | Samsung Electromechanics | RC1005F103CS | Resistors 10k | 402 |  |  | 0.063 W | Surface Mount |  | 0.1 | 0.1 | link (https://www.digikey.com/en/products/detail/panasonic-electronic-components/ERA-2AEB103X/1706029)
4 | C2A,C2B | 2 | Samsung Electromechanics | CL05A226MQ5N6J8 | Capacitor 22 µF | 402 | 6.3V |  |  | Surface Mount |  | 0.13 | 0.26 | link (https://www.digikey.com/en/products/detail/samsung-electro-mechanics/CL05A226MQ5N6J8/7320595)
3.3 V
Item # | *Ref Des | *Qty | Manufacturer | *Mfg Part # | Description / Value | *Package |  |  |  | Type | Your Instructions / Notes | Unit Cost | Total Cost | Website
37 | U33 | 1 | Texas Instruments | TLV75533PDYDR | 3.3 V LDO | SC-74A | 5.5 V |  |  | Surface Mount |  | 0.29 | 0.29 | link (https://www.digikey.com/en/products/detail/texas-instruments/TLV75533PDYDR/22531567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)
7 | C35, C36 | 2 | Samsung Electromechanics | CL05A105KP5NNNC | Capacitor 1uF | 402 | 10V |  |  | Surface Mount |  | 0.08 | 0.16 | link (https://www.digikey.com/en/products/detail/samsung-electro-mechanics/CL05A105KP5NNNC/3886734)
13 | D2 | 1 | onsemi | SM5817PL-TP | Schottky Diode | SOD-123 | 20V | 500 mA |  | Surface Mount |  | 0.15 | 0.15 | link (https://www.digikey.com/en/products/detail/onsemi/MBR0520LT1G/918574?msockid=3be78e2c27cf64fd084798ba26146572)

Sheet: Motor 4S Conversion
Voltage (V) | Current (A) | Thrust (G) | Power (W) | Efficieny (G/W) | Speed (RPM)
16.8 | 1.4674 | 133.2 | 24.61536 | 5.411255411 | 5629.48
16.8 | 2.668 | 222 | 44.7552 | 4.96031746 | 7036.85
16.8 | 3.6018 | 310.8 | 60.41952 | 5.144032922 | 8250.79
16.8 | 6.2031 | 399.6 | 104.05584 | 3.840245776 | 9311.32
16.8 | 8.2708 | 488.4 | 138.74112 | 3.520225294 | 10245.12
16.8 | 31.9493 | 972.36 | 535.94352 | 1.814295656 | MAX

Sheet: Motor 3S Conversion
Voltage (V) | Current (A) | Thrust (G) | Power (W) | Efficieny (G/W) | Speed (RPM)
12.6 | 1.1 | 75 | 13.86 | 5.411255411 | 4220
12.6 | 2 | 125 | 25.2 | 4.96031746 | 5275
12.6 | 2.7 | 175 | 34.02 | 5.144032922 | 6185
12.6 | 4.65 | 225 | 58.59 | 3.840245776 | 6980
12.6 | 6.2 | 275 | 78.12 | 3.520225294 | 7680
12.6 | 23.95 | 547.5 | 301.77 | 1.814295656 | MAX

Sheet: Motor Data Conversion
Motor DataSheet (2-blade) (https://drive.google.com/drive/folders/1x5aC58c-gUP96v3wH80yv_gIQ1_BFy-2)
14.8 V 4S
Thrust
Weight (lbs): | 3.895
Hover Weight (g) | 1766.742281
Ascend Weight (g) | 3533.484562
Hover per motor (x4) (g): | 441.69
Ascend per motor (x4 - Double) (g): | 883.3711406
Power
Interpolation between 300g and 500g (P442) (W): | 87.574
P340 Total (W) | 350.2971494
Interpolation between 700g and 900g (P884) (W): | 226.189
P680 Total (w) | 904.7543139
Current | 10.5 V | Current | 11.1 V | Current | 12.6 V
Hover per motor Current (A) | 8.340408318 | Hover per motor Current (A) | 7.889575436 | Hover per motor Current (A) | 6.950340265
Hover Total Current (A) | 33.36163327 | Hover Total Current (A) | 31.55830174 | Hover Total Current (A) | 27.80136106
Ascend per motor Current (A) | 21.54176938 | Ascend per motor Current (A) | 20.37734941 | Ascend per motor Current (A) | 17.95147448
Ascend Total Current (A) | 86.16707752 | Ascend Total Current (A) | 81.50939765 | Ascend Total Current (A) | 71.80589793
Efficiency
Hover Efficiency (g/W) | 5.043553122
Ascend Efficiency (g/W) | 3.905463072

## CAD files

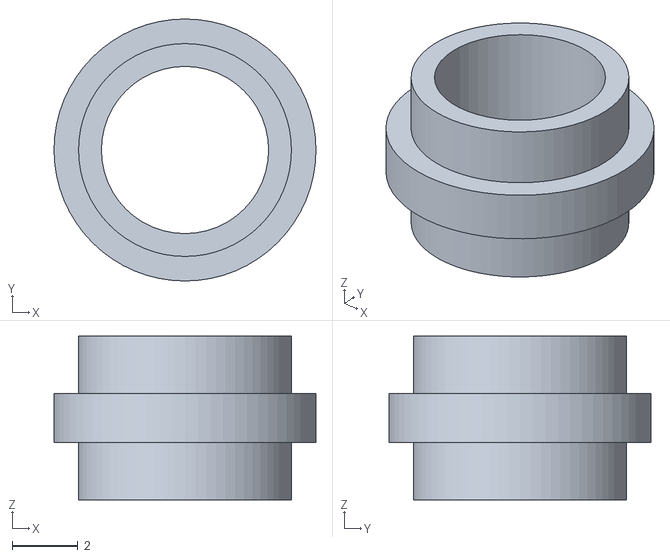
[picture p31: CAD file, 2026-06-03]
design/mechanical/Mari_LED_mount.stl
8.00 x 8.00 x 5.00

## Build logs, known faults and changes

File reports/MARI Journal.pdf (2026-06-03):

# MARI Quadcopter Drone

Connor Lee Prior
Department of Engineering
CSU East Bay
connorprior2000@gmail.co
m

Christopher Ruiz-Guerra
Department of Engineering
CSU East Bay
cruizguerra@horizon.csueast bay.edu

Nahom Solomon
Department of Engineering
CSU East Bay
nsolomon@horizon.csueastb
ay.edu

Seth Iris Canonigo
Department of Engineering
CSU East Bay
scanonigo@horizon.csueastb ay.edu

### Abstract

The MARI drone group developed subsystems to work together and achieve a flight controller. We’ve created software that reads data from a BNO055 Inertial measurement unit (IMU) and a BMP39 to extract Roll, Pitch, Yaw, temperature and relative altitude via I2C lines. We selected to use a STM32F756BG microcontroller running on the maximum speed of 216 MHz in conjunction with a Proportional-Integral-Derivative (PID) control loop. This system allows real time adjustments based on the user's PWM outputs from a radio transmitter and outputs PWM signals driving our Electronic Speed Controllers to our motors. We developed a Printed Circuit Board (PCB) which has three dedicated and separate power domains, utilizes a switching regulator to lower 14.8V to a 5V domain and a Low-Dropout regulator to drop 5V to 3.3V
We then utilized a long-range radio (LoRa) module to wirelessly transmit data over a kilometer which communicates with the microcontroller over a simple UART connection using Attention commands (AT). This allows us to see data from the IMU and
BMP390 & PID coefficients in real time. We’ve created a MARI LoRa Monitor which uses a PyQt6 framework to parse through the LoRa data packet and updates a live Graphical User Interface (GUI) with telemetry of PID coefficients. Despite the lack of stable flight, we have validated power in all domains, and established PID communication on the three axes. We’ve overcome catastrophic hardware failures, including the burning three boards. These failures helped the team learn the value of power system planning, circuit design, hardware bring-up, hardware validation, firmware programming on microcontrollers, we all got experience in PCB and schematic design and lastly, the value of working together as a team.

### Introduction

For our Senior Design project we decided to create a quadcopter drone. This project posed multiple design challenges that helped us better understand both the circuit board design and programming needed to build a drone that can actually fly. Instead of using a prebuilt system that we could just plug in and use out of the box, we had to design our own printed circuit board. This introduces problems for power distribution for sensitive components, interpreting communication signals through protocols such as I2C and UART, wirelessly transmitting data into a human-readable format, and choosing the right parts that are able to meet the design criteria we set out to reach.
As a flying quadcopter is an inherently unstable system, another big component of this project was stabilizing the drone by making high frequency adjustments to the motors to maintain the drone’s position. This involves using a Proportional-Integral-Derivative control loop to make microadjustments to the outputs to the motors.
In this article we will describe our process for creating our quadcopter drone, the problems we encountered when designing it, and how we solved them.

### Hypothesis

When looking at features we wanted for our quadcopter drone, the main things we were looking for was for it to be remote controlled, self-balancing, and for the user to be able to add any additional modules onto the drone if they wanted to. To do this, we first needed a microcontroller, so we could control our propellers with computer programming. For our remote control, we used a radio controller which would send radio signals from the user to our receiver on the drone. For the drone to self-balance, we needed to add an Inertial Measurement Unit (IMU). This allows us to detect the angular acceleration of the drone in accordance with pitch, roll, and yaw, which is very important to stabilizing the drone. We also added a barometer to be able to set conditions that would limit the height the drone could fly at. For telemetry, we used a long-range radio (LoRa) module to wirelessly transmit data to us mid-flight. Finally, we made sure we had a lot of extra pins we could access on the microcontroller so we could add additional components later down the line.

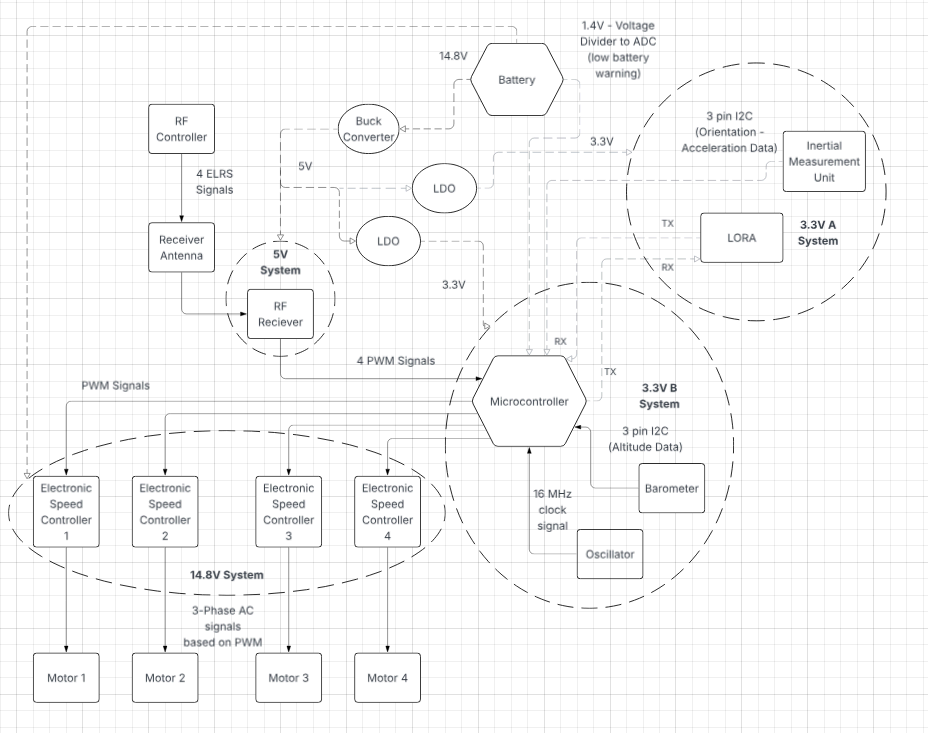
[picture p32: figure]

### Block Diagram

Our project has a few different subsystems that work together to get our drone flying. The first of these is the microcontroller, the brain of the system. We had chosen the STM32F756BG as our microcontroller. By programming the microcontroller, we can use that logic to control the outputs to our motors based on both the user inputs and the data from the IMU. We also decided to hook our microcontroller up to a crystal oscillator to speed up the clock frequency of our microcontroller to the maximum speed of 216 MHz.
The main two sensors we used in the project were the BNO055 IMU and the BMP390 Barometer. The main purpose of the IMU is to send acceleration and position data of the drone to the microcontroller. To keep track of linear acceleration, the IMU has an accelerometer. The accelerometer is a MEMS (Micro
- Electro - Mechanical Systems) accelerometer, which works by keeping track of the movement of a small mass that is in contact with multiple springs, which are in turn connected to silicon plates. The mass forms a capacitor with the plates, and the capacitance of that system can be measured. As the mass accelerates in any direction, the capacitance of the mass and the plate in that direction increases as the distance decreases. By tracking the difference in capacitance, the accelerometer can track the acceleration of the sensor in any direction. The gyroscope uses a similar system, and tracks the angular velocity using the capacitance of a mass and plate. Finally, the BNO055 includes a third sensor, a magnetometer, which tracks changes to the magnetic field in relation to the sensor by tracking voltage changes resulting from the Lorenz force on a current-carrying conductor. These 3 different sensors are then combined together natively on the BNO055 using their “sensor fusion” algorithm to act as a Kalman Filter which is a method for getting more accurate data by using the data from other sensors to correct errors in the data from a single sensor. A Kalman filter works by first defining a state variable, which is a vector containing the different variables that need to be tracked. The Kalman Filter then predicts the change in orientation for the next timestep using a mathematical model, similar to how you would use a given speed and time to calculate the distance traveled. The algorithm then uses sensors to measure the orientation, and compares it to the predicted orientation. Finally, it weighs these two values and combines them according to a given Kalman gain. After the Kalman Filter algorithm calculates the orientation of the drone, these values are then sent to the microcontroller, which will adjust the outputs to the motors so the drone will self-correct if it is out of position. The IMU uses the I2C protocol to communicate with our microcontroller.
For our user control, we went with a prebuilt radio controller, which would send data using radio signals to a radio receiver, which would in turn send data using Pulse Width Modulated (PWM) signals to our microcontroller. We needed 4 different signals to allow the user to control throttle (up/down), pitch (tilt forward/back), roll (tilt left/right), and yaw (turn left/right). This allows the drone to move freely in 3 dimensions.
Once the microcontroller has taken the user inputs and adjusted those values based on the measurements from the IMU, the next step is to turn those into outputs to the motors. These are also PWM signals that will be sent to our 4 Electronic Speed Controllers (ESCs). The main purpose of the ESCs is to act as an interface between the microcontroller and the motor. The microcontroller is a sensitive component that operates at low voltage and low current, while the motors need high voltage and high current. The ESCs bridge this gap by interpreting the PWM signals from the microcontroller into the 3-phase power the motor needs to spin its magnets in a circle.
All of this is controlled by our power system, which can be split into three voltage domains: 3.3V, 5V, and 14.8V. For our 14.8V domain, we simply hook up the battery. Next, we drop that voltage to 5V using a buck converter, which uses a switching regulator to lower the 14.8V from our batter to 5V. After that we use a Low-Dropout regulator to drop the 5 volts to 3 volts.

### Lora

To monitor the drone during flight testing and PID tuning, we needed a way to wirelessly transmit sensor data, motor outputs, and system status from the drone back to a ground station. We chose LoRa as the wireless link because it offers long range (over a kilometer in open conditions) at very low transmit power, and uses an inexpensive, easy-to-integrate module, the Reyax RYLR998, that communicates with the microcontroller over a simple UART connection using AT commands.
However, LoRa has one major drawback for telemetry: the available bandwidth is very limited. The core physical-layer transmission parameters for LoRa are spreading factor, bandwidth, coding rate, and preamble length. These parameters determine the tradeoff between range, robustness, throughput, and airtime. For LoRa, a higher spreading factor lowers the symbol rate, increases receiver sensitivity, and extends communication range, but it also makes each packet take longer to transmit. The same general tradeoff also applies to bandwidth: narrower bandwidth improves RF sensitivity (which increases range) but increases transmission time. Coding rate adds forward error correction, improving robustness against data loss at the cost of extra overhead, while a longer preamble can improve reception reliability against noise but it also adds airtime. [4] [5]
For our settings, we had chosen a spreading factor of 7, 125 kHz bandwidth, 4/5 coding rate, and 8 preamble symbols a single packet takes between 45 and 75 milliseconds to transmit depending on the byte size of the payload. This was determined using the tested throughput in the datasheet [1]. The specific reasons will be elaborated in detail when explaining the challenges of LoRa telemetry. Regardless, designing the telemetry system was therefore mostly an exercise in deciding what data was important enough to send, how often to send it, how to format it efficiently, and ultimately make tradeoffs between range, noise, and transmission time.
One side of the link consists of the STM32 connected to a RYLR998 module by UART and the other side consists of a PC connected to another RYLR998 module by UART, which is connected to a USB-UART TTL device. The module handles all the LoRa physical-layer details internally and exposes a text-based AT command interface to the host. To send a message, the host writes an AT+SEND command to the module specifying the destination address, payload length, and ASCII data. When a message is received on the other end, the receiving module emits a line of the following form on its UART:

+RCV=<address>,<length>,<data>,<RSSI>,<SNR> [2]

The five fields contain the sender's address, the number of bytes in the payload, the actual data we sent, the received signal strength indicator (RSSI, in dBm), and the signal-to-noise ratio (SNR, in dB). For example, a real line received during a test flight looks like:
+RCV=1,28,I:1245|0.38,-6.19,5.00,26.8,996.9,-65,8

The RSSI and SNR fields are added by the receiving module itself based on the radio conditions when the packet arrived. They give us a real-time measure of link quality independent of the message contents, which is useful for telling whether dropped packets are due to range issues, interference, or other causes.
The LoRa modem provides a transparent byte-level link, but it does not know anything about what kind of data we are sending. To distinguish, for example, IMU data from motor outputs, and to detect packets that get lost in transit, we designed our own message format that lives inside the data field of each LoRa packet:

TYPE:SEQ|PAYLOAD

The type tag is a short identifier for what type of data the packet contains. The sequence number is an integer that increments by one for each message of that type. The payload is a comma-separated list of values whose meaning depends on the type. For example, an IMU reading is sent as:

I:124|0.38,-6.19,5.00,26.8,996.9

This says: message type I (IMU and Barometer), sequence number 124, with five payload values in fixed positions (pitch in degrees, roll in degrees, yaw in degrees, temperature in Celsius, pressure in hPa).

### LORA Message Types

Message Type | Meaning | Payload contents
I | IMU and Barometer Outputs | pitch, roll, yaw, temperature, pressure
M | Motor mix PWM Outputs | front-left, front-right, rear-left, rear-right outputs
P | PID terms and components | pitch P, pitch I, pitch D, roll P, roll I, roll D, yaw P, yaw I, yaw D,
B | Battery status | Battery state (NORMAL | WARNING | CRITICAL)
R | Task rates | flight, tele tx, tele rx, housekeeping
C | CPU usage | flight, tele tx, tele rx, housekeeping, idle
RW | Raw text | Any string
MARI | Special Ping reply | Fixed 88-byte response to a ground-station ping

We had chosen this specific format, because
it was relatively easy for the receiving link, which is
connected to our python application, to parse and sort data efficiently according to the message type. And by including an incrementing sequence number, the TYPE:SEQ effectively a pseudo-UUID, making detection of missing or duplicate packets easier to debug.
One of the challenges of the LoRa telemetry is finding correct parameters and finding the balance between transmission airtime vs range, robustness, and reliability. Because of the amount of packets being sent per second as well as close range, we ended up sacrificing distance for lowering transmission time, hence why those specific parameters. The exception being Bandwidth and Coding Rate, both of which are not worth changing for little reduction on time. As shown in the graph below, reducing the Spreading Factor to 7 greatly reduces the transmission time per payload bytes compared to the default of 9.

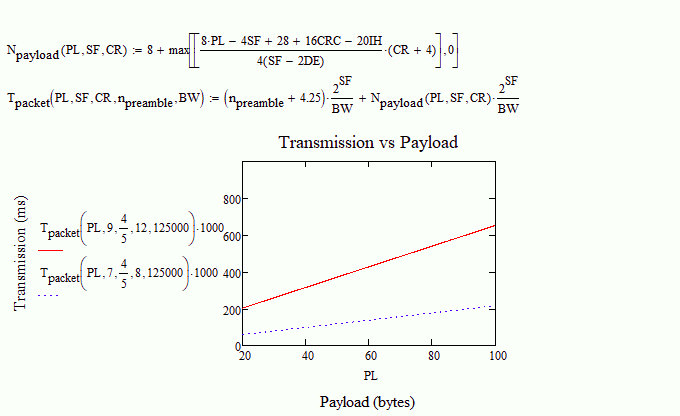
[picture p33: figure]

### Schematic References:

Power System

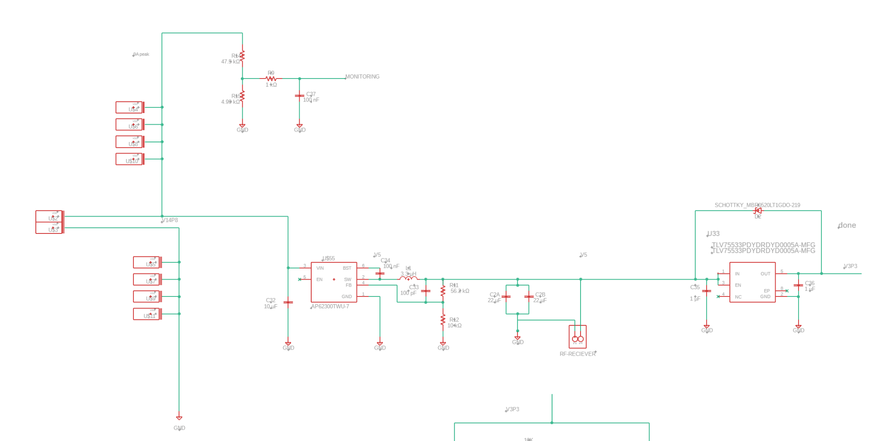
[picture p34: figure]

Microcontroller 1

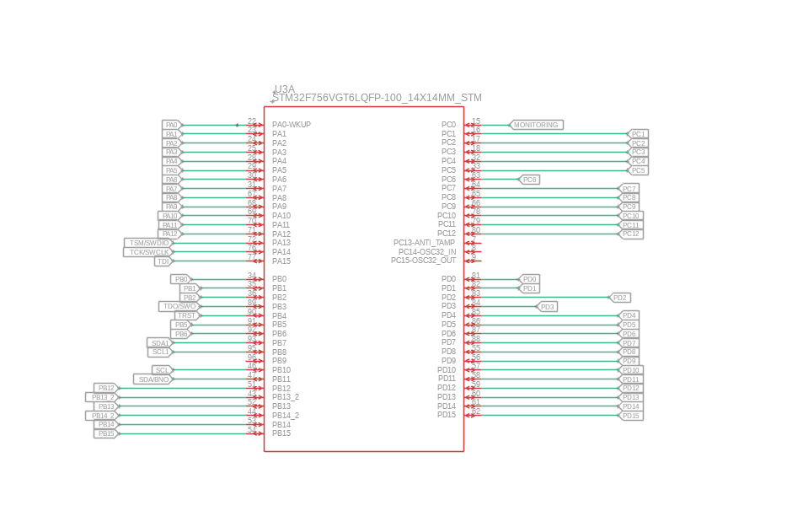
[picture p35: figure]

Microcontroller 2

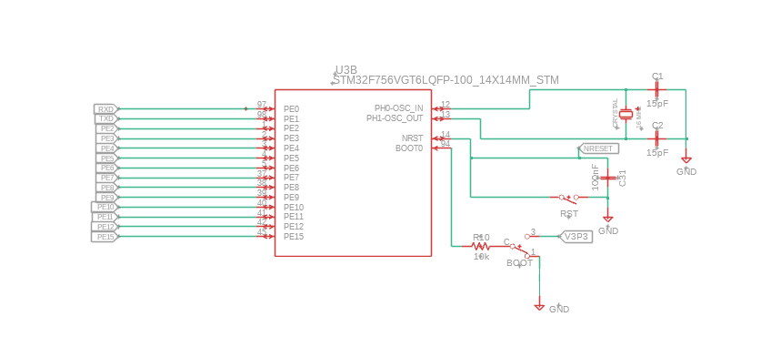
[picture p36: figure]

Microcontroller 3

Inertial Measurement Unit

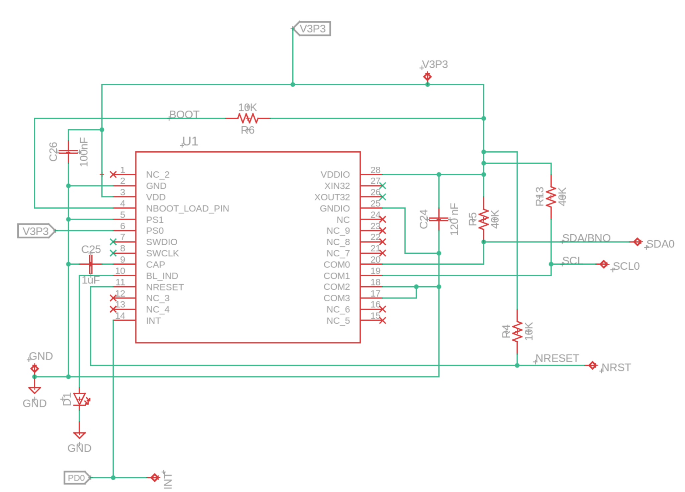
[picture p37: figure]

Barometer

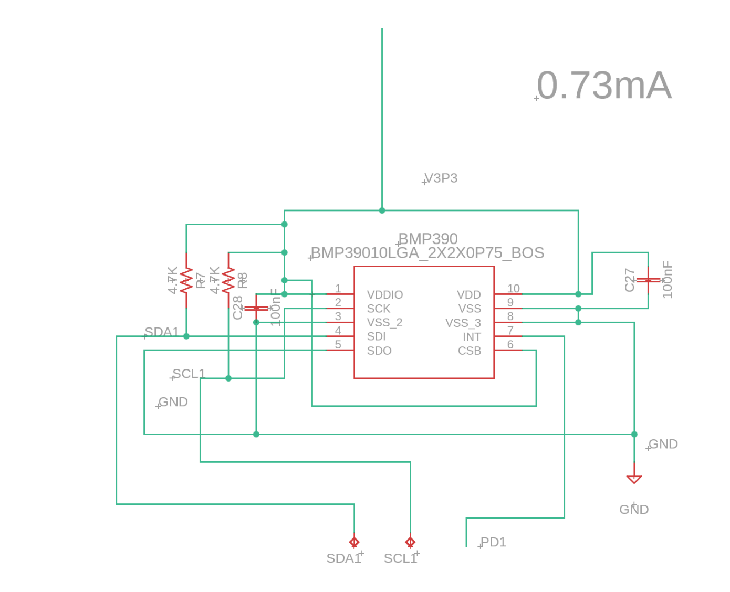
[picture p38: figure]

### Schematic Descriptions

Power System:
The Mari drone Power system is designed to use a single battery to support multiple voltage domains. The system can operate on either a 3S or 4S Lipo battery, with nominal voltages of 11.1V and 14.8V, respectively. Supporting both configurations provides flexibility, but it also requires components to be compatible with the voltage range. Power calculations were performed using the nominal 4S voltage of 14.8 V.
The battery directly powers four ESCs and motors. The motors require the largest share of total power in the system. The lower-voltage components are supported through regulators. After the ESCs and motors, the battery's voltage is stepped down using a buck converter to 5V, then to two separate 3.3V domains using LDOs for sensitive components like the microprocessor and sensors.

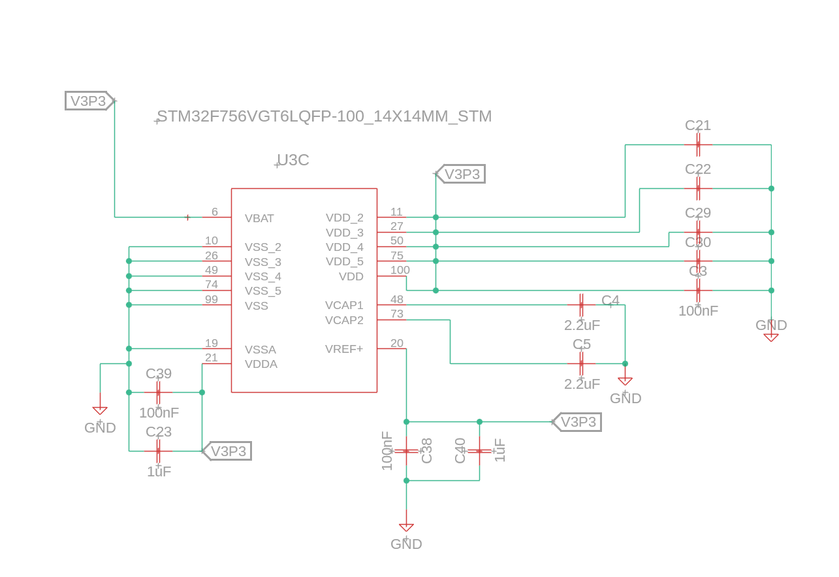
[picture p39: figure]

To calculate the total system demand, the power of each subsystem was calculated using

P = V × I

For the Motors and ESCs, each draws
I | , so the total current is motors = 23. 232 A

Imotors,total = 4 × Imotors

Imotors,total = 92. 928 A

The monitoring circuit draws
I | and is included in the monitoring circuit = 0. 322 mA
total current calculation.

P

14.8V = V
battery

× (Imotors,total + Imonitoring circuit

)

P

14.8V = 1375. 33 W

For the regulated subsystems, the 5V and 3.3V rails are calculated as

P

5V = 5. 0V × I
5V,total

P

5V = 3. 364 W

P

3.3V = 3. 3V × I
3.3V,total

P

3.3VA = 0. 537 W

P

3.3VB = 1. 081 W

The total system power is then

P

total = P

14.8V + P

5V + P

3.3VA + P
3.3VB

P

total = 1380. 318 W

The results show that the motors and ESCs accounted for most of the power consumption, compared with the 5V and 3.3V subsystems, which consumed significantly less power but remained critical for system control. To improve voltage stability and reduce noise, LC filtering and bypass capacitors were included throughout the design. During initial testing, the system was prone to voltage spikes from the battery, which had not been taken into account. This issue was resolved by adding Anti-Spark XT90 connectors to the battery terminals and a bulk capacitor at the PCB input to smooth the input voltage and reduce transient effects. The battery monitoring circuit was also included to measure the voltage and provide feedback via LEDs when voltage levels approached unsafe conditions.

Microcontroller:
As the microcontroller is connected to every other system, most of the pins are used to connect to other systems, or to the header pins we can use to optionally add other systems to our drone. Diagram 1 consists mostly of these types of connections, while Diagram 2 also includes our BOOT circuit and crystal oscillator circuit. Schematic 3 includes the bypass capacitors used for the microcontroller, as well as the main connections to the power system. While not exactly an error, we misunderstood the function of the BOOT circuit in this schematic. We thought it would turn the microcontroller on/off by cutting it from power, but what it really does is switches one of the operating modes of the microcontroller.

Inertial Measurement Unit:
For our inertial measurement unit, we used the recommended schematic from the datasheet for the BNO055. This means connecting all of our I2C data lines to the microcontroller (SDA, SCL and INT), hooking up the power lines to the 3.3V domain, and making sure we had pull-up resistors and bypass capacitors where required.
One error we encountered in this schematic was the PS0 pin was supposed to be set to GND, but was instead set to 3.3V. This ended up changing the “mode” of the communication from I2C to HID over I2C, which made it effectively impossible to communicate with the tools we were using. While we tried to fix the problem with soldering, it ended up being too difficult to fix. We ended up having to use our extra pins on our microcontroller to hook up to an external BNO055 module to keep the use of the IMU.

Barometer:
The barometer schematic is very similar to the IMU schematic, in that we followed the recommended schematic from the datasheet and hooked up the 3 I2C data lines to the microcontroller, as well as connecting it to our 3.3V domain.

### PCB Layout 1

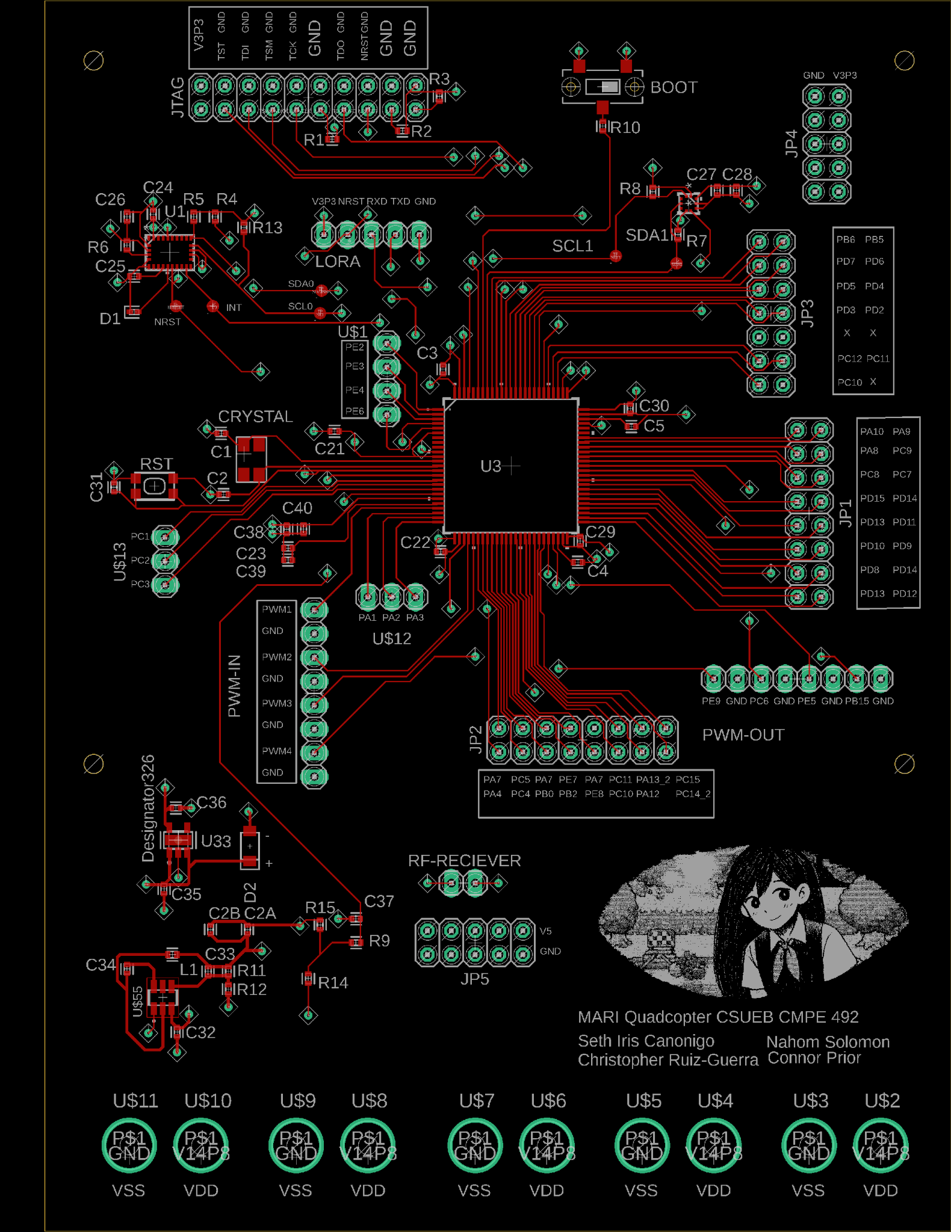
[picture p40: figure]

Overall, our PCB holds our power system, microcontroller, IMU, and barometer, and is split according to voltage domain., with the top being the 3.3V domain, the bottom being the 14.8V domain, and a small space in the middle for the 5V domain. Our overall strategy was to keep sensitive
components as close to other components as possible, while keeping the voltage domains as clear and separate as possible.
One thing to note in the layout is we used a 4 layer board for our PCB. The red traces are on the top layer, the two middle layers are VDD and ground, and the bottom layer holds the blue traces. Having a bottom layer allows us to route traces much easier, as we can effectively cross traces without shorting them together.

Microcontroller/IMU/Barometer:

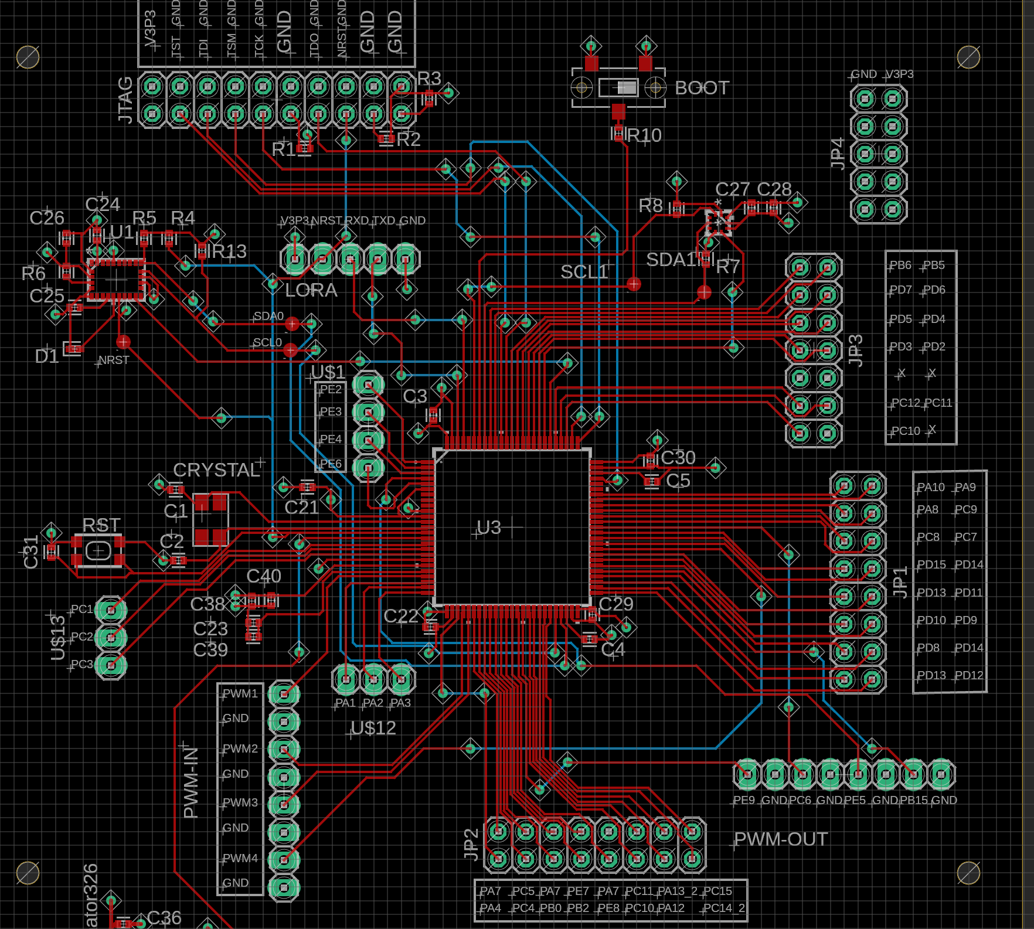
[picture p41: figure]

The microcontroller is definitely the hub of the board, with connections to almost every component on the PCB. The traces follow the schematic exactly, allowing us to easily connect components on our layout based on the schematic. This layout also shows the many extra pins our microcontroller can use to connect to any external components we might want to add later down the line. We made sure to add identifiers to these pins in the silkscreen, as having to reference the schematic constantly to know which pin was which is too much work. Some pins of note are the JTAG pins on top of the board. These are the pins we connect to our programmer to program our microcontroller.
The IMU and Barometer layout follow the schematic precisely. However, since the pins on the component are under the component, we decided to add test points to almost all of the traces coming out of the IMU, as they would become impossible to access during testing if something went wrong.

Power System:

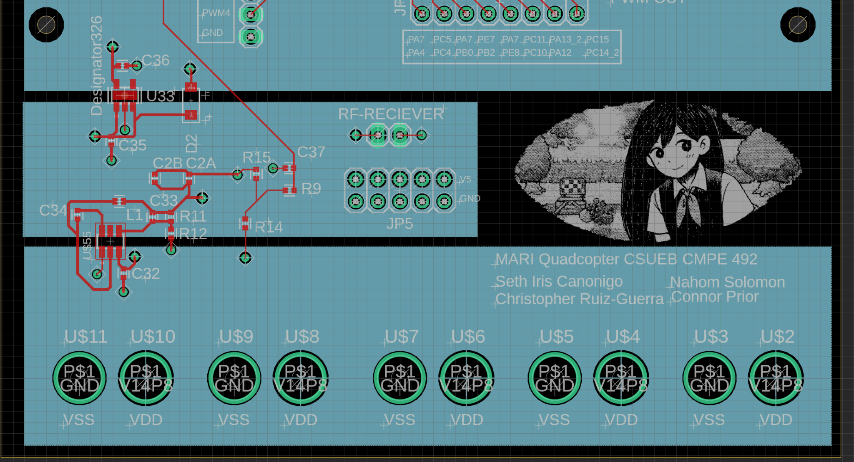
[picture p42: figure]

The power system allows us to bridge between clearly defined voltage domains. The bottom part is the 14.8V domain. These throughholes are intended to be used to hold bullet connectors to connect to 5 different components: the 14.8V battery and the 4 ESCs. The layout clearly shows the 14.8V domain being connected to the 5V domain with the Buck Converter, and the 5V domain being connected to the 3.3V domain with the LDO.
One error we encountered in this layout is the indicators for the Shottky diode. Since we weren’t completely aware of the conventions of labelling the anode and cathode of the diode, it ended up being reversed in assembly. This had devastating consequences and resulted in two boards with unusable components. Once we found the problem, it was a simple fix. We just had to switch the diode around and the system worked as intended.

### PCB Layout 2

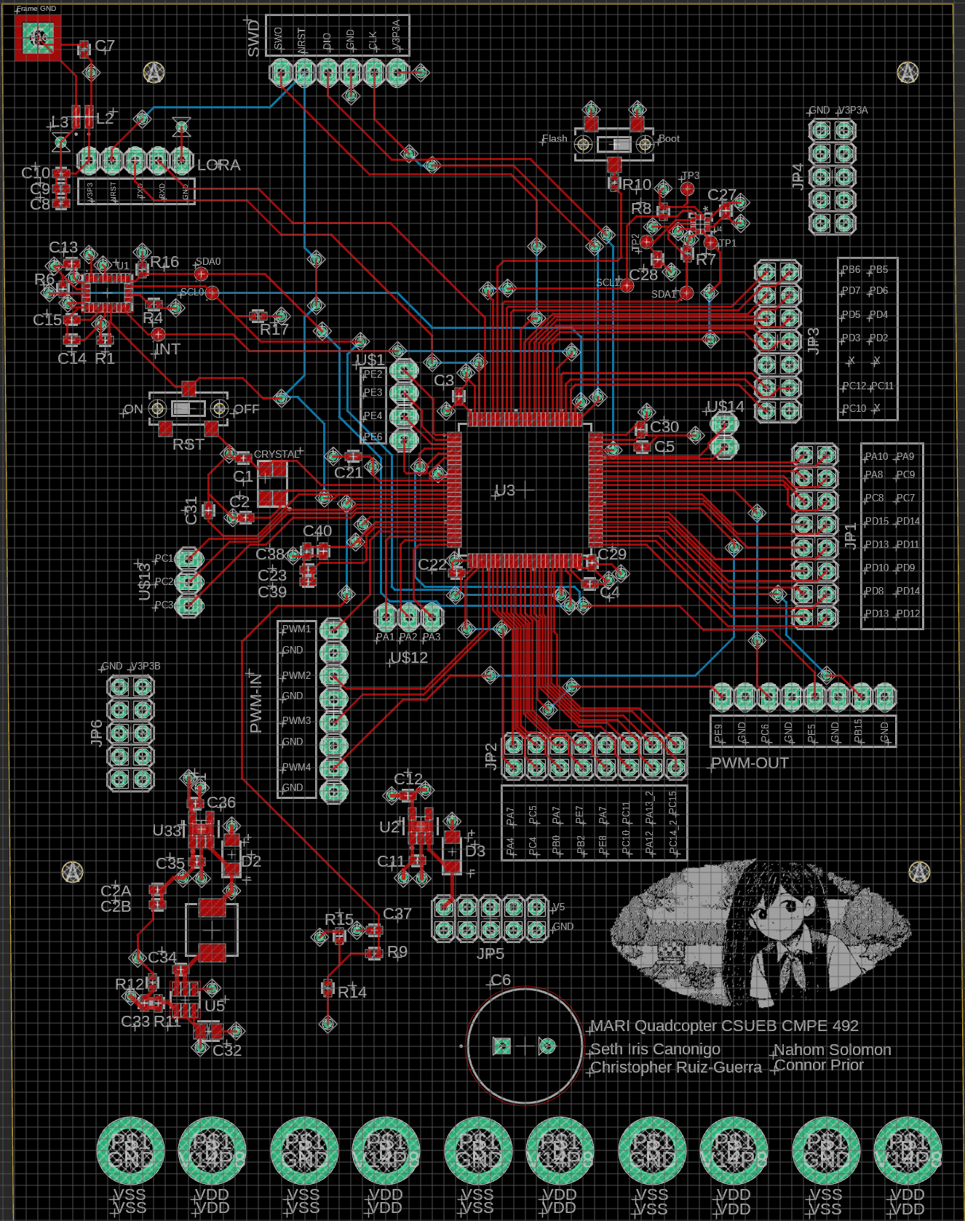
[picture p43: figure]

After burning multiple boards and having trouble with the IMU connection, we did a new layout to fix the old problems. The main changes to the new layout are a large capacitor in the 14.8V domain and a larger inductor after the Buck Converter to handle higher voltages. We also cleaned up some of the pins we thought were unnecessary and corrected the IMU connection.

### Software

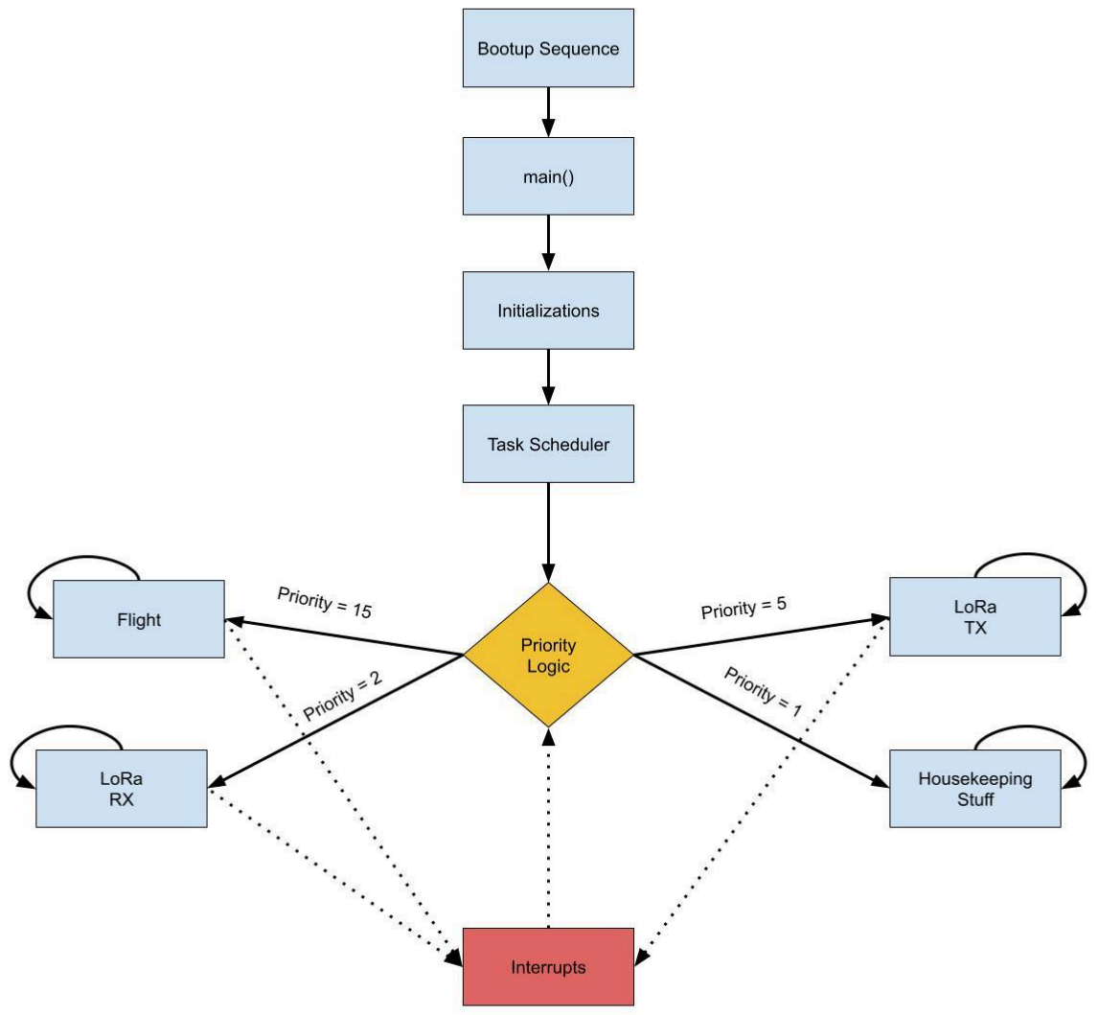
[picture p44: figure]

While initially being a single continuous control loop, the software component of our project now is mainly running a real-time operating system (RTOS), specifically FreeRTOS, because the different parts of our software have different priorities with very different timing requirements. For example, the flight control has a hard deadline, being that it can risk crashing the drone if the flight controls do not run fast enough. Other components like telemetry, barometer reading, and battery reading are less important and can even risk a bottleneck, slowing down the flight calculation time. An RTOS lets us guarantee that the time-critical code always runs when it needs to, even if a slower task is in the middle of doing something else. With the RTOS, the overall software is then divided into four main tasks, each running at its own rate and priority: FlightTask, TelemTxTask, TelemRxTask, and HousekeepingTask.

FlightTask:

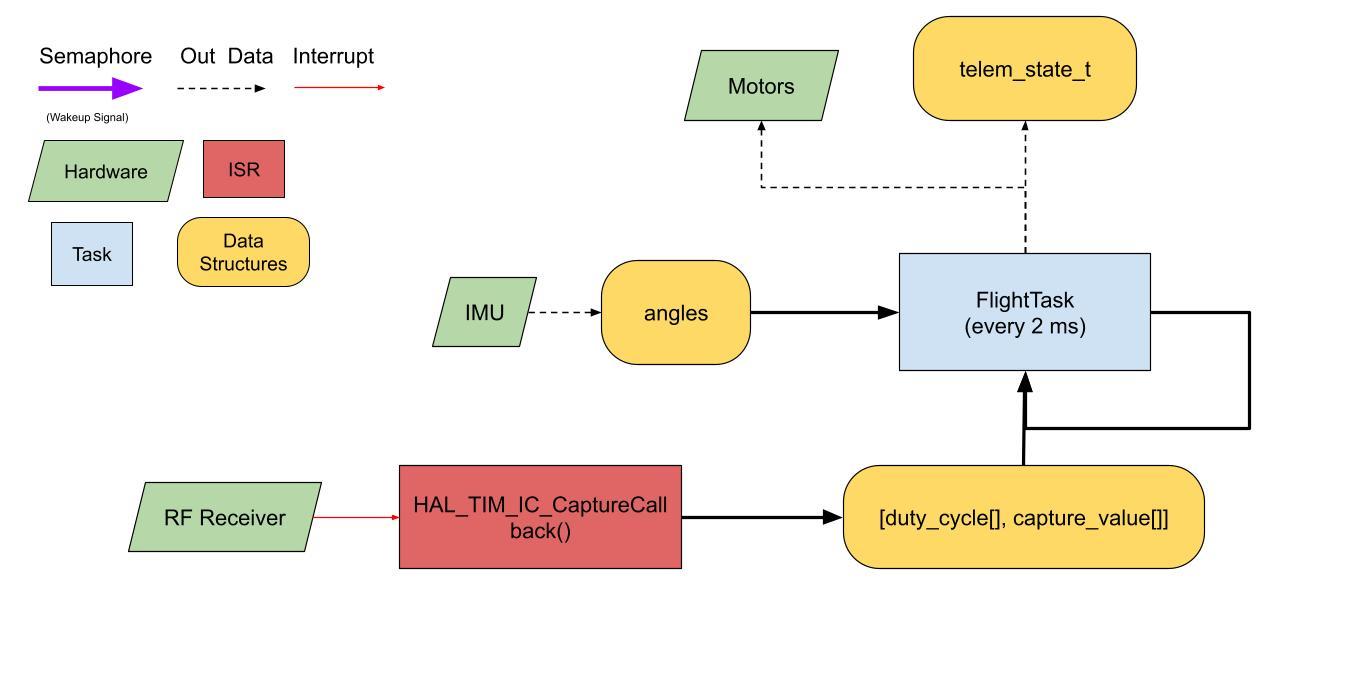
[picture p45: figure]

The most important task is FlightTask, which runs the flight control loop at 500 Hz, meaning it has only 2 milliseconds to read the IMU, compute pitch, roll, and yaw errors, run three PID controllers, apply the mixing equations, and update the four motor PWM outputs. Since it has the highest priority, it preempts whatever lower-priority task is currently running.

First, we have to implement timers to keep track of all the PWM signals we are taking from the radio receiver and outputting to the ESCs. We also initialize the settings on the sensors to make sure they're working properly. We can then move on to the control loop.
To start, we read the user input using timers to determine the duty cycle of the PWM signal. Then, we read data from the registers of the IMU and barometer. After that, we calculate the error between the data from the user input and the IMU. Then its time to use the PID equations.

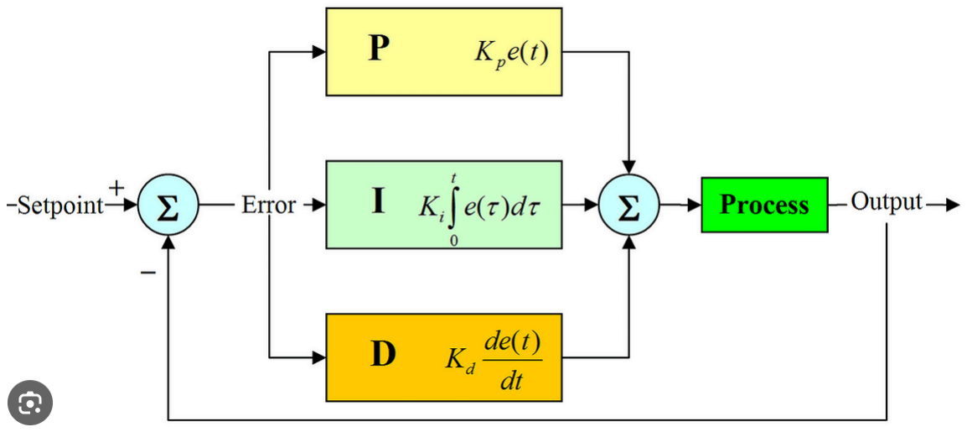
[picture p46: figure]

Essentially, the idea of PID equations is to take the error and multiply it by each of the three parts of PID: Proportional, Integral, and Derivative. You then have to manually tweak constant K until your system corrects the error quickly.
Finally, we use mixing equations to turn the intention of the user to outputs to the motors according to whether they want to increase/decrease throttle/roll/pitch/yaw:

Motor1(Front Left) = throttle - roll - pitch + yaw Motor2(Front Right) = throttle + roll - pitch - yaw Motor3(Rear Right) = throttle + roll + pitch + yaw Motor4(Rear Left) = throttles - roll + pitch - yaw

This completes the control loop and we go back to the beginning.

TelemTxTask:

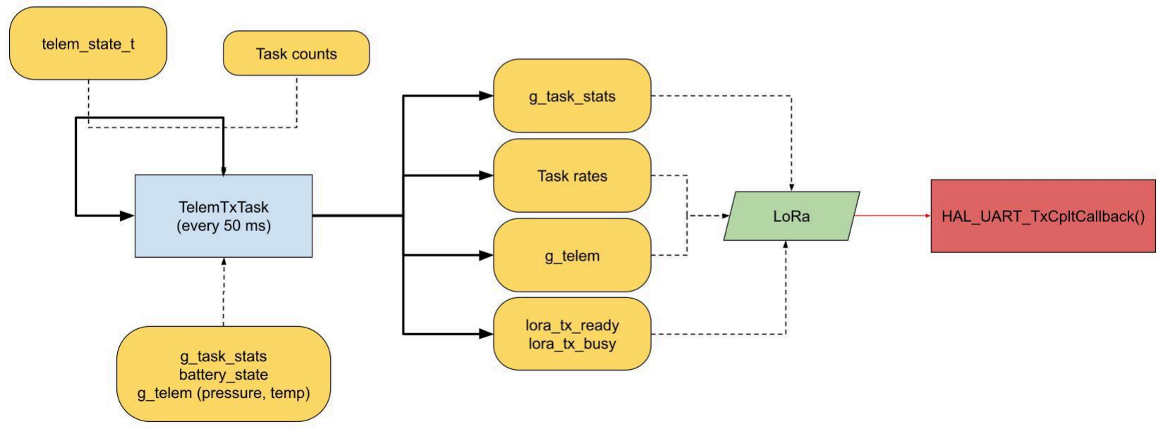
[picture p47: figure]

The second most important task is the TelemTxTask. This task decides what to send and when to send it. It runs at 20 Hz, woken every 50 milliseconds by tick polling. Each time the task runs, it does three things: take a snapshot of the latest data from the HousekeepingTask and FlightTask, prepare it for the message scheduler, and call into the message scheduler to actually send something to UART with the specific AT+SEND command. Instead of blindly transmitting every message every cycle, which would massively exceed the LoRa link's capacity, the scheduler implements a round-robin over the message types with two layers of gating: ‘+OK’ check and message type rate limiting.
Since every TX signal AT+SEND sends back an RX signal +OK, the scheduler will always wait until it receives it or wait a one second timeout. This is to prevent overrunning the LoRa. Also since some message types are more important than others, like IMU data vs CPU usage, message types also have priority among each other. The scheduler will send some data with a certain message type more often than others.

TelemRxTask:

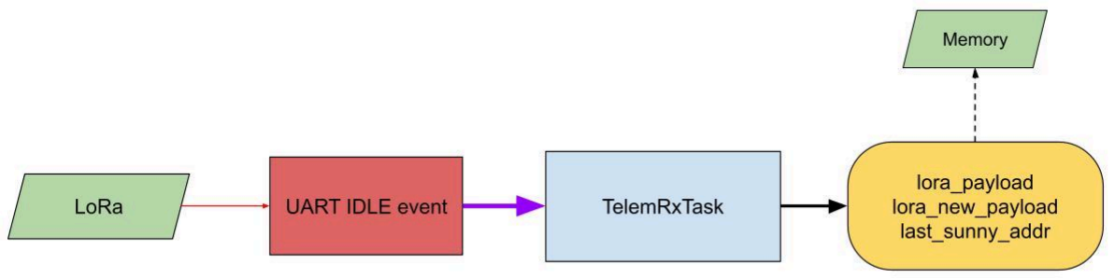
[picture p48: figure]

The second least important task is TelemRxTask. Unlike the other three tasks, this task is fully interrupt-driven.When the ground station finishes sending a line over UART, a hardware "idle line" interrupt fires, which releases a semaphore that wakes TelemRxTask to parse the message. This keeps the time between a command arriving and the drone responding to it to a few microseconds, instead of polling the UART in software. There is so far only one command available, which is ‘pinging’ the drone.

HousekeepingTask

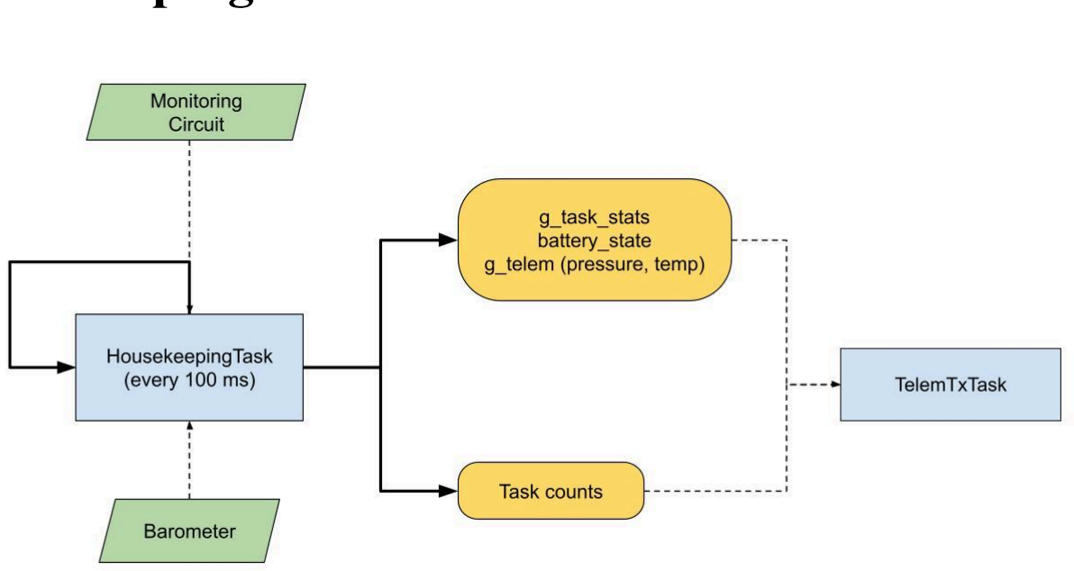
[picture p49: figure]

The lowest ‘default’ task is the HousekeepingTask. Unlike the other three tasks, this task is fully periodic, running every 100 ms when neither FlightTask nor TelemTxTask is running. All this task does is to record the task rates and the CPU usage, run the barometer, run battery monitoring logic, and simply output them to the global variables where the TelemTxTask can access them.

One of the biggest challenges is configuring the speed of polling for the tasks that are both very fast, but also preventing starvation. This was the case for FlightTask, where initially it was given a 1 ms polling period (1 kHz). Unfortunately, because IMU reading plus the PID calculating was over 1 ms, this resulted in FlightTask essentially running forever, starving TelemTxTask and HousekeepingTask, preventing any data from being transmitted. Our solution was to essentially quadruple the I2C bus speed and doubling the period for FlightTask.

MARI LoRa Monitor (Ground Station):

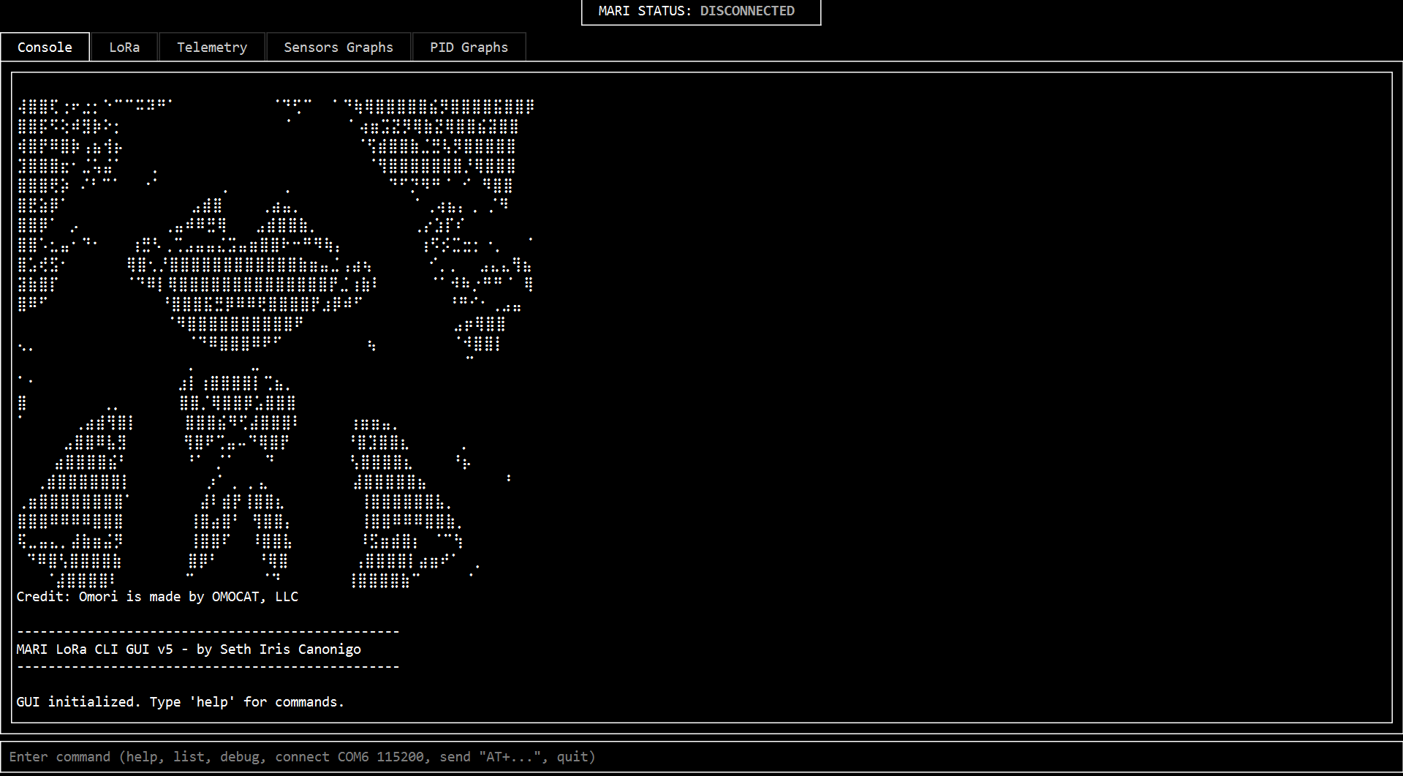
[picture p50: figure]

To monitor the drone mid-flight, we developed a desktop Python application using the PyQt6 framework called the ‘MARI LoRa Monitor’. The application is connected to the second RYLR998 through a USB-UART TTL device. It receives the +RCV messages, parses them into readable data according to the LoRa message type table, and updates a live dashboard as shown below.

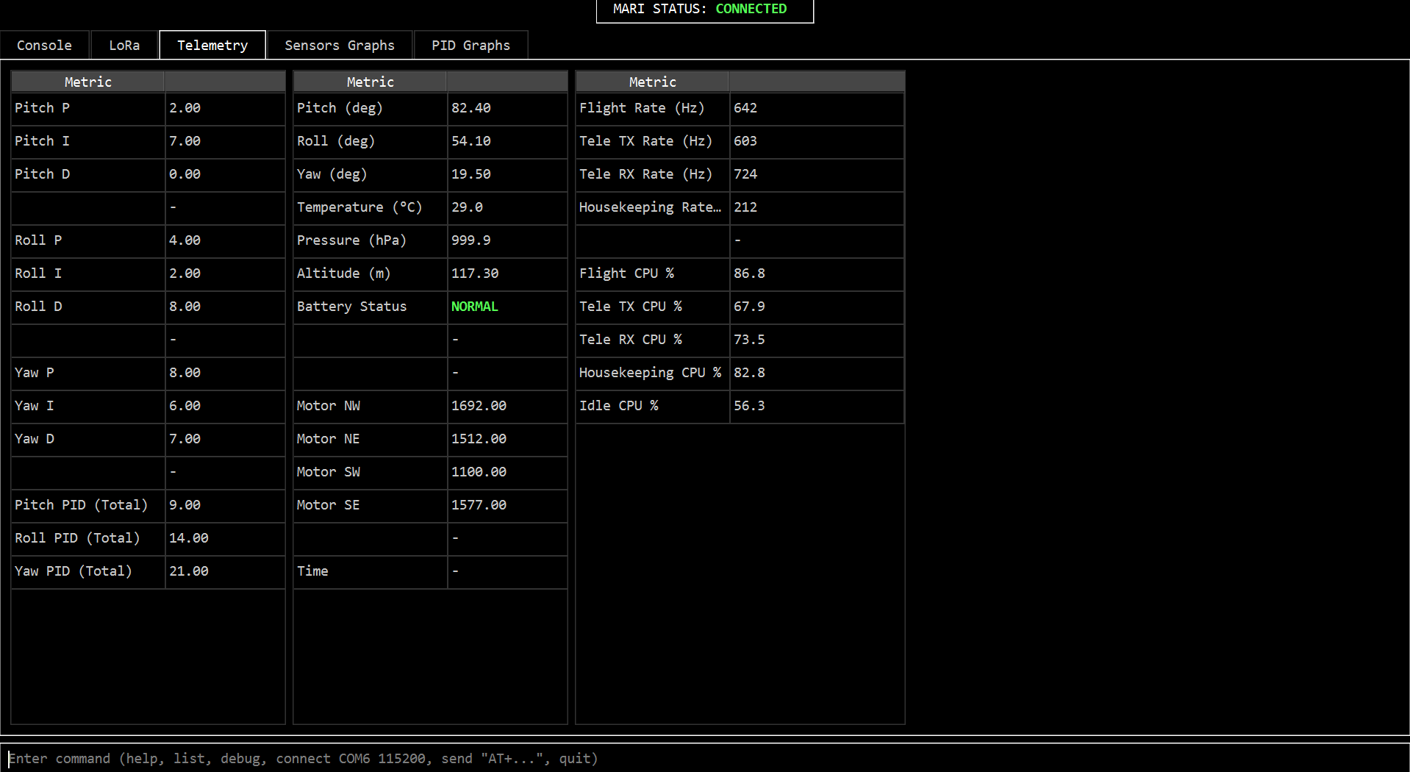
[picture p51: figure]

### Results

Overall, while we have come a long way to finishing the drone project, we still have a long way to go to completing it. This is due to the problems we encountered in our power system and the pins we got wrong in the development of the PCB. However, we have still made good progress. The power system is now completely functional and the software is working as intended. While the IMU on the board is no longer working, we have used an external module that works fine. The overall power consumption of our system ended up being 1091.9W. The total cost of the components on the PCB came to $45.52. However, in reality each board was about $100 each to construct. The off-board components added up to around $330. Therefore, the total cost for an individual drone was about $430.

### Conclusion

Overall, we still have plenty to work on with our drone project. While all of our systems work, we still need to tune the PIDs to get stable flight to help the drone stay in the air. One of the main lessons we learned was how difficult the power system was to get right. Having a good understanding of the fundamentals of circuits will always be very important when designing systems like this drone. We also learned how important step-by-step verification is. It is very hard to debug a system when you’re not sure what the problem is. Finally, we learned how important being able to see data while testing is. It is a lot easier to debug when you can notice patterns in the data and form hypotheses based on it.

### Works Cited

[1] Bosch Sensortec, BNO055 Intelligent 9-axis absolute orientation sensor,
BST-BNO055-DS000-18, October 2021
[2] REYAX Technology Co., Ltd., RYLR998 UART Interface 868/915 MHz LoRa Antenna Transceiver Module Datasheet, 27-Feb-2025, “Data Throughput Test,” p. 10.
[3] REYAX Technology Co., Ltd., LoRa AT Command Guide: Apply for RYLR998, RYLR498, 7-Aug-2025, “+RCV Show the received data actively,” p. 8.
[4] F. Adelantado, X. Vilajosana, P. Tuset-Peiro, B. Martinez, J. Melià-Seguí, and T. Watteyne, “Understanding the limits of LoRaWAN,” IEEE Communications Magazine, vol. 55, no. 9, pp. 34–40, 2017, doi: 10.1109/MCOM.2017.1600613.
[5] Semtech Corp., SX1272/3/6/7/8 LoRa Modem Design Guide, application note AN1200.13, Rev. 1, Jul. 2013, sec. 4, “The LoRa Packet Format & Time On Air,” p. 7.

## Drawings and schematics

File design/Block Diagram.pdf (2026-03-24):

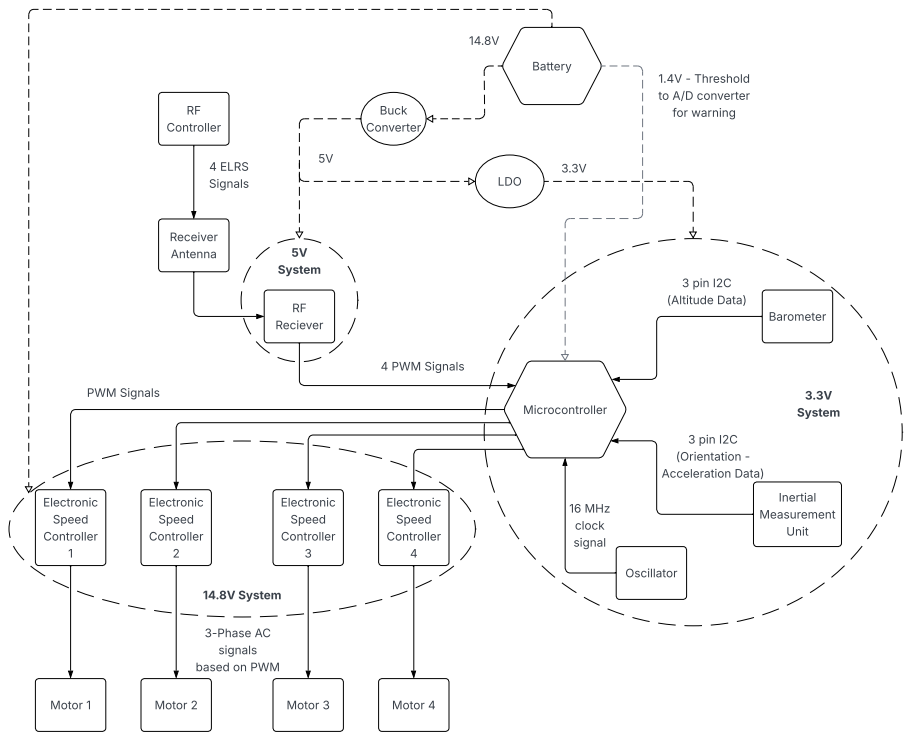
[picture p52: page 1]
Buck Converter; Receiver Antenna; RF Reciever; Inertial Measurement Unit; Microcontroller; Electronic Speed Controller 4; Electronic Speed Controller 3; Electronic Speed Controller 2; Electronic Speed Controller 1; Motor 1; Motor 2; Motor 3; Motor 4; Oscillator; 3 pin I2C (Orientation - Acceleration Data); 16 MHz clock signal; PWM Signals; 3.3V System; 14.8V System; Battery; 4 PWM Signals; Barometer; 5V System; LDO; 4 ELRS Signals; RF Controller; 3 pin I2C (Altitude Data)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

3-Phase AC
signals
based on PWM

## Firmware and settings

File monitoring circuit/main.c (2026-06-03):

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
/* Includes ------------------------------------------------------------------*/
#include "main.h"

/* USER CODE BEGIN PD */
#define ADC_MAX_COUNT          4095.0f
#define ADC_REF_VOLTAGE        3.3f

#define BAT_R1                 47500.0f
#define BAT_R2                 4700.0f

/* (12.6 V / 3S) Monitoring Circuit Values */

#define GREEN_ON   11.4f
#define GREEN_OFF  11.2f
#define YELLOW_ON  10.5f
#define YELLOW_OFF 10.7f

/* (16.8 V / 4S) Monitoring Circuit Values

#define GREEN_ON   14.2f
#define GREEN_OFF  14.0f

#define YELLOW_ON  13.2f
#define YELLOW_OFF 13.4f

*/

/* USER CODE END PD */

ADC_HandleTypeDef hadc1;

/* USER CODE BEGIN PV */

uint32_t adc_raw = 0;
float battery_voltage = 0.0f;
int battery_state = 2; // start as green (or 1 if you prefer)

/* USER CODE END PV */

void SystemClock_Config(void);
static void MPU_Config(void);
static void MX_GPIO_Init(void);
static void MX_ADC1_Init(void);
/* USER CODE BEGIN PFP */
uint32_t Read_ADC_Value(void);
float Read_Battery_Voltage(void);

/* USER CODE END PFP */

/**
  * @brief  The application entry point.
  * @retval int
  */
int main(void)
{

  /* MPU Configuration--------------------------------------------------------*/
  MPU_Config();

  /* MCU Configuration--------------------------------------------------------*/

  /* Reset of all peripherals, Initializes the Flash interface and the Systick. */
  HAL_Init();

  /* Configure the system clock */
  SystemClock_Config();

  /* Initialize all configured peripherals */
  MX_GPIO_Init();
  MX_ADC1_Init();
  /* Infinite loop */
  /* USER CODE BEGIN WHILE */
  while (1)
  {
    /* USER CODE END WHILE */

    /* USER CODE BEGIN 3 */

	  battery_voltage = Read_Battery_Voltage();

	  // State Machine
	  if (battery_state == 2) // green
	  {
	      if (battery_voltage < GREEN_OFF)
	          battery_state = 1;
	  }
	  else if (battery_state == 1) // yellow
	  {
	      if (battery_voltage >= GREEN_ON)
	          battery_state = 2;
	      else if (battery_voltage < YELLOW_ON)
	          battery_state = 0;
	  }
	  else // red
	  {
	      if (battery_voltage >= YELLOW_OFF)
	          battery_state = 1;
	  }

	  // LED output
	  if (battery_state == 2)
	  {
	      HAL_GPIO_WritePin(GPIOA, GPIO_PIN_10, GPIO_PIN_SET);
	      HAL_GPIO_WritePin(GPIOA, GPIO_PIN_11, GPIO_PIN_RESET);
	      HAL_GPIO_WritePin(GPIOA, GPIO_PIN_12, GPIO_PIN_RESET);
	  }
	  else if (battery_state == 1)
	  {
	      HAL_GPIO_WritePin(GPIOA, GPIO_PIN_10, GPIO_PIN_RESET);
	      HAL_GPIO_WritePin(GPIOA, GPIO_PIN_11, GPIO_PIN_SET);
	      HAL_GPIO_WritePin(GPIOA, GPIO_PIN_12, GPIO_PIN_RESET);
	  }
	  else
	  {
	      HAL_GPIO_WritePin(GPIOA, GPIO_PIN_10, GPIO_PIN_RESET);
	      HAL_GPIO_WritePin(GPIOA, GPIO_PIN_11, GPIO_PIN_RESET);
	      HAL_GPIO_WritePin(GPIOA, GPIO_PIN_12, GPIO_PIN_SET);
	  }

	  HAL_Delay(200);

  }
  /* USER CODE END 3 */
}

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
/* USER CODE BEGIN 4 */

uint32_t Read_ADC_Value(void)
{
    uint32_t sum = 0;

    for (int i = 0; i < 16; i++)
    {
        HAL_ADC_Start(&hadc1);
        HAL_ADC_PollForConversion(&hadc1, HAL_MAX_DELAY);
        sum += HAL_ADC_GetValue(&hadc1);
        HAL_ADC_Stop(&hadc1);
    }

    return (sum / 16);
}

float Read_Battery_Voltage(void)
{
    float v_adc;

    adc_raw = Read_ADC_Value();
    v_adc = ((float)adc_raw / ADC_MAX_COUNT) * ADC_REF_VOLTAGE;
    battery_voltage = v_adc * ((BAT_R1 + BAT_R2) / BAT_R2);

    return battery_voltage;
}

/* USER CODE END 4 */

 /* MPU Configuration */

void MPU_Config(void)
{
  MPU_Region_InitTypeDef MPU_InitStruct = {0};

  /* Disables the MPU */
  HAL_MPU_Disable();

  /** Initializes and configures the Region and the memory to be protected
  */
  MPU_InitStruct.Enable = MPU_REGION_ENABLE;
  MPU_InitStruct.Number = MPU_REGION_NUMBER0;
  MPU_InitStruct.BaseAddress = 0x0;
  MPU_InitStruct.Size = MPU_REGION_SIZE_4GB;
  MPU_InitStruct.SubRegionDisable = 0x87;
  MPU_InitStruct.TypeExtField = MPU_TEX_LEVEL0;
  MPU_InitStruct.AccessPermission = MPU_REGION_NO_ACCESS;
  MPU_InitStruct.DisableExec = MPU_INSTRUCTION_ACCESS_DISABLE;
  MPU_InitStruct.IsShareable = MPU_ACCESS_SHAREABLE;
  MPU_InitStruct.IsCacheable = MPU_ACCESS_NOT_CACHEABLE;
  MPU_InitStruct.IsBufferable = MPU_ACCESS_NOT_BUFFERABLE;

  HAL_MPU_ConfigRegion(&MPU_InitStruct);
  /* Enables the MPU */
  HAL_MPU_Enable(MPU_PRIVILEGED_DEFAULT);

}

/**
  * @brief  This function is executed in case of error occurrence.
  * @retval None
  */
void Error_Handler(void)
{
  /* USER CODE BEGIN Error_Handler_Debug */
  /* User can add his own implementation to report the HAL error return state */
  __disable_irq();
  while (1)
  {
  }
  /* USER CODE END Error_Handler_Debug */
}
#ifdef USE_FULL_ASSERT
/**
  * @brief  Reports the name of the source file and the source line number
  *         where the assert_param error has occurred.
  * @param  file: pointer to the source file name
  * @param  line: assert_param error line source number
  * @retval None
  */
void assert_failed(uint8_t *file, uint32_t line)
{
  /* USER CODE BEGIN 6 */
  /* User can add his own implementation to report the file name and line number,
     ex: printf("Wrong parameters value: file %s on line %d\r\n", file, line) */
  /* USER CODE END 6 */
}
#endif /* USE_FULL_ASSERT */

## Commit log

2026-03-24 docs: add Mathcad simulations for static and dynamic power analysis
    - Integrated Mathcad (.xmcd) worksheets for 12.6V and 16.8V battery configurations.
    - Documented mathematical models for voltage drop, trace width validation, and thermal dissipation.
    - Included dynamic power simulations to verify rail stability under peak motor loads (70A+).
    - Validated RC filter and decoupling capacitor arrays (1000uF - 2200uF) for EMI suppression.
2026-03-24 docs: integrate 12.6V-16.8V power budgets and flight endurance models
    - Uploaded Power Budget V2.xlsx featuring updated 4S (16.8V Max) loading profiles.
    - Documented 71.6A peak ascent current requirements for the primary motor bus.
    - Modeled system behavior across the full voltage swing (16.8V full charge to 12.6V nominal).
    - Included multi-domain efficiency modeling (90-95%) for Buck and LDO stages.
    - Added flight endurance projections (9.4 min hover / 3.6 min ascent) based on 3000mAh 70C discharge.
    - Indexed passive component selections including 2200uF bulk capacitors for ripple mitigation.
    [Power Budget V1.xlsx, Power Budget V2.xlsx]

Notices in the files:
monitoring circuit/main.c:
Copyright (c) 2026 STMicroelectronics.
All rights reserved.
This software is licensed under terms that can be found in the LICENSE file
